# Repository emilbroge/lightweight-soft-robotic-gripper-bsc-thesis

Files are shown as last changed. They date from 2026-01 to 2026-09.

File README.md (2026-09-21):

# Bio-Inspired, Lightweight Soft Robotic Gripper

A lightweight, tendon-driven soft robotic gripper developed as a Bachelor’s thesis at DTU (Neuro Robotics Technology Lab) by Mads August Claussen and Emil Broge Johansen.

The goal of this project was to design a compliant gripper that weighs almost nothing (only 37 g at the wrist!) so it can be mounted onto soft, low-payload continuum robotic arms without weighing them down. Instead of rigid fingers with lots of gears, it uses flexible 3D-printed fingers shaped like an octopus tentacle that wrap gently around objects of different shapes and sizes.

This repository contains the 3D printing/casting files, the Arduino firmware, and the raw experimental data collected for the gripper. It is written so that a future student can pick the project back up: print/cast the parts, wire up the electronics, flash the firmware, and reproduce (or extend) the tests.

https://github.com/user-attachments/assets/c0556c12-12d1-4bf8-a20e-e9f583e94eb2

*(If you are viewing this locally, check out `documentation/gripper-showcase-vid.mp4` and `documentation/gripper_being_operated_and_powered_off.mp4` to see it in action!)*

---

## 1. System Architecture & Mechanism

To keep the hand as light as possible, we separated the "muscles" from the "fingers":

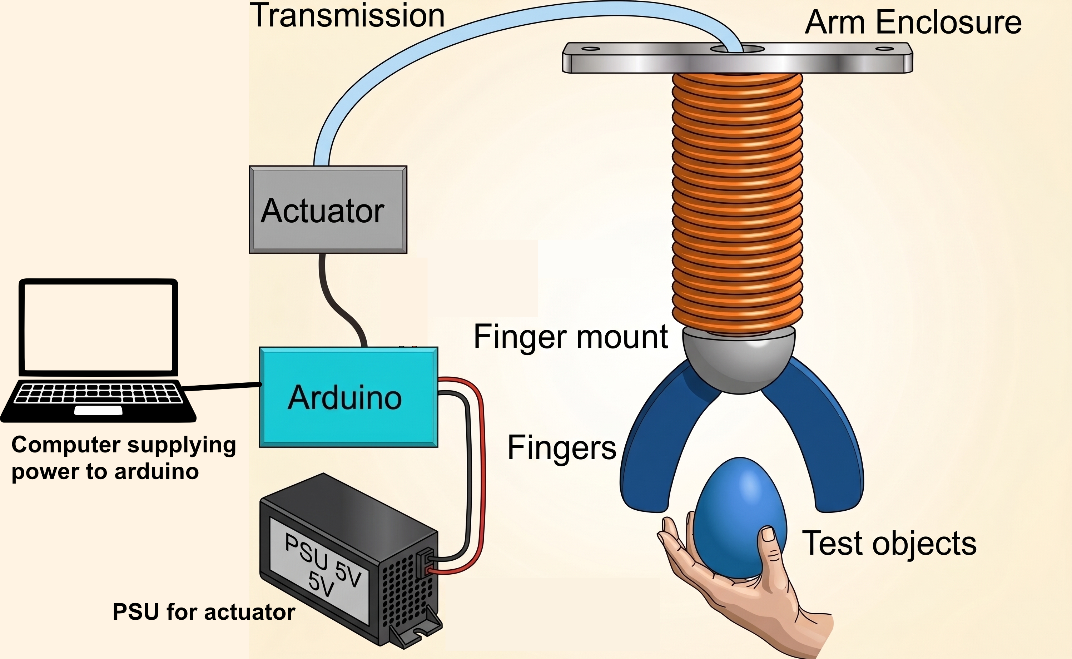
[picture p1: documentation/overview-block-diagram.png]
Gripper System Overview|300


- **External Actuator Box:** Two smart servo motors sit away from the moving arm. One pulls the "flexor" tendon to close the grip, and the other pulls an "extensor" tendon to open it and add stiffness.
- **Bowden Cable Transmission:** The pulling force travels through slick PTFE tubes via strong polyethylene cords (Dyneema).
- **Cable Drum Wrist:** Inside the mount, small spools turn linear cable pulling into rotation without needing a bulky mechanism.
- **Octopus-Inspired Fingers:** The fingers are printed out of flexible TPU with built-in bending joints. They follow a logarithmic spiral shape so they naturally wrap around objects instead of pinching at a stiff angle.
- **Silicone Skin:** A soft silicone layer gives the fingers the grip they need so objects don't slip out.

**Below the gripper can be seen being operated.**

https://github.com/user-attachments/assets/960f5932-b7c9-4243-a79a-f50e997e1e70

---

## 2. Hardware Build Guide

The entire physical build uses affordable 3D-printed parts, standard hobbyist bearings, and two smart servos. The brain of the setup is an Arduino Uno fitted with a motor shield.

All step-by-step guides and CAD drawings are organized in the `documentation/` folder:
- **Parts List & Costs:** See the [Bill of Materials (PDF)](documentation/bill_of_materials.pdf)
- **Step-by-Step Mechanical Assembly:** See the [Assembly Guide (PDF)](documentation/assembly_instructions.pdf)
- **Fabrication & Print Specs:** See the [Hardware & Fabrication Guide](documentation/README.md#1-3d-printing--fabrication)
- **Full Thesis Report:** Read [Full BSc Report (PDF)](documentation/Full_BSc_Report.pdf) for the academic background, math, and design decisions.

---

## 3. Code & Electronics Build Guide

The microcontroller firmware is set up in `code/bsc-gripper/`. It handles motor communication, runs an automatic grip sequence, and streams diagnostic data.

- We use **PlatformIO** (via the VS Code extension) to compile and upload code automatically. [Setting up PlatformIO](code/bsc-gripper/PlatformIO.md)
- **Wiring & Pinout:** See the [Wiring Setup in documentation](documentation/README.md#2-electronics--wiring-setup).
- **Firmware Architecture & Motor Tuning:** See the [Firmware Deep-Dive](code/bsc-gripper/README.md) for pinouts, state machine explanations, and tuning constants in `config.h`.

---
## 4. Experimental Data (`raw_data/`)

All raw test data from our validation trials are available in `raw_data/`:
- `transmission_test/`: Tendon transmission efficiency measurements and `transmission_test.py` to calculate friction coefficients ($\mu$).
- `motor_performance_test/`: Current and force measurements for XL330 and XL430 servos.
- `finger_mount_test/`: Structural and mechanical load data for the finger mount.
- `payload_test/`: Pull-force test data across 11 test shapes (`test_objects.csv` describes dimensions and weights).
- `success_rate/`: Grasp trials (`data_succes.csv`) on real everyday objects.

---

## 5. Potential Improvements

If you're picking up this project for a semester project or thesis, here are several clear areas where you can take it further:

### Hardware Improvements
- **Miniaturization & Cleaner Enclosure:** Redesign the motor box to be smaller and more self-contained. Adding buttons directly to the enclosure would make manual testing much smoother (for example, triggering test routines or toggling live serial output).
- **Easier Finger Assembly:** Threading the tendons and securing the fingers to the mount currently requires a very specific touch and patience. A more modular, snap-in joint design would save a lot of headaches.
- **Self-Contained Power:** The prototype currently relies on a 5V benchtop power supply and a tethered laptop. Integrating a small internal regulator or battery pack would make the setup truly portable.
- **Tendon Terminations:** Finding a cleaner mechanical method to clamp the tendon ends (rather than manual knots) would make string tensioning and length adjustment much more repeatable.
- **User interface:** A simple GUI on a laptop or tablet could allow users to control the gripper, run test routines, and visualize live data without needing to dig into the Arduino code.

### Control Improvements
- **Scientifically Grounded Control:** The current firmware uses a tuned open-loop control. A great next step would be modeling the gripper movements analytically—for instance, using the approach from:
  > Z. Wang and N. M. Freris, *"Exploiting Frictional Effects to Reproduce Octopus-Like Reaching Movements with a Cable-Driven Spiral Robot,"* 2024 IEEE 7th International Conference on Soft Robotics (RoboSoft), San Diego, CA, USA, 2024, pp. 537-542.
- **Grasp Detection:** Use live motor current readings to detect when the fingers touch an object and stop pulling automatically.

---

## Notes for the Next Student

Don't hesitate to reach out, if you have any questions about the project. We are happy to help you get started and point you in the right direction.

- **Mads August Claussen**
- **Emil Broge Johansen**

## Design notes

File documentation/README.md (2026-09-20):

# Hardware & Fabrication Documentation

This guide provides the mechanical and fabrication specifics needed to print, cast, assemble, and wire the gripper.

---

## 1. 3D Printing & Fabrication

All design files are located in the `3d_files/` directory in both editable `.step` and slicer-ready `.stl` formats.

### Recommended Print Settings

| Part | File | Material | Slicer Notes |
|---|---|---|---|
| **Fingers** | `Finger - with supports.stl` | TPU 95A | Print flat on side. Use the version with built-in supports from the file. Speed: 20–30 mm/s. |
| **Finger Mount** | `Finger mount.step` | PLA < PETG < PA-CF | 4+ perimeters, Note: This is very delicate. |
| **Cable Drums** | `Finger mount - * drum half.stl` | PLA < PETG < PA-CF | 100% infill for shaft rigidity. |
| **Arm Interface** | `Finger mount - Arm Interface Cap.stl` | PLA < PETG < PA-CF | Standard print settings (0.2 mm layer height). |
| **Silicone Mold** | `Finger mold.stl` | PLA / PETG | Smooth layer lines help with demolding. |

### Silicone Coating
1. Print the monolithic TPU fingers.
2. Mix a soft 2-part addition-cure silicone rubber.
3. Either pour silicone into `Finger mold.stl` around the finger, or dip-coat the gripping surface. The small retention loops on the finger will lock the cured silicone in place mechanically so it doesn't peel off under shear forces.

---

## 2. Electronics & Wiring Setup

The system uses an **Arduino Uno** with a stacked **Robotis DYNAMIXEL Shield**.
> Future version could use OpenRB-150 instead.

### Pin Connections

| Arduino Pin | Variable in `config.h` | Connection / Device |
|---|---|---|
| **Pin 2** | `DXL_DIR_PIN` | Dynamixel Shield Direction Pin |
| **Pin 4** | `BTN_PIN` | Grip toggle button (connect between Pin 4 and GND) |
| **Pin 5** | `ABC_LOAD_CELL_CLK` | HX711 Clock (optional test rig) |
| **Pin 6** | `C_LOAD_CELL_DT` | HX711 Data (optional test rig) |
| **Pin 7** | `DXL_SHIELD_UART_RX` | SoftwareSerial RX (for computer debug printing) |
| **Pin 8** | `DXL_SHIELD_UART_TX` | SoftwareSerial TX (for computer debug printing) |
| **Pin 9** | `SCOPE_PIN_A` | Timing test pin |
| **Pin 10** | `SCOPE_PIN_B` | Timing test pin |

### Power Supply Warning
> **Warning:** You **must** provide external 5V power to the screw terminals on the DYNAMIXEL Shield. The USB cable alone only powers the Arduino board; the motors will not respond, and the initialization code will hang in a ping loop until external power is supplied. This should be fixed in a future version.

---

## 3. Assembly References

For detailed mechanical assembly steps, see the PDFs included in this folder:
- **`assembly_instructions_compressed.pdf`**: Exploded-view diagrams showing how to press-fit the bearings, assemble the drums, route the cords, and attach the unit to the robot arm. > [!NOTE]
> The flexor and extensor tendon pairs must be equal in length to prevent asymmetrical finger movement during flexion and extension.
- **`bill_of_materials_compressed.pdf`**: Itemized list of fasteners, bearings, wire, tubing, and electronics with part numbers and supplier links.

The getting the wires through the fingers can be tricky. Contact us for tips if you are having trouble.

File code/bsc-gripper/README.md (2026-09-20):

# Gripper Firmware Guide (`code/bsc-gripper`)

This folder contains the PlatformIO firmware project targeting an Arduino Uno (`env:uno` in `platformio.ini`) equipped with a Robotis DYNAMIXEL Shield.

> **Legacy Firmware Note:** The earlier non-PlatformIO firmware (`code/main_firmware_version/`) has been deprecated and superseded by this project.

---

## 1. Project Structure & Responsibilities

| File | Purpose / Responsibility |
|---|---|
| `src/main.cpp` | Main loop, button debounce, state machine, periodic sampling, and serial formatting. |
| `src/config.h` | All hardware pins, tuning parameters, motor IDs, safety limits (PWM/Current), load cell scale factor, and timing periods. |
| `src/dynamixel_control.{h,cpp}` | DYNAMIXEL communication via `Dynamixel2Arduino`, sync-write packet packing, feedback reading, and the grip state machine (`dxl_update_state()`). |
| `src/load_cell.{h,cpp}` | Reading and calibrating the optional HX711 load cell sensor (active when `debugLoadCells = true`). |
| `src/serial_config.{h,cpp}` | Configures `SoftwareSerial` pins for telemetry output. |

---

## 2. Crucial Hardware Quirks

### 1. The Single Hardware UART on Arduino Uno
The Arduino Uno has only one hardware serial port (`Serial`, pins 0 and 1). This hardware port is entirely dedicated to the high-speed half-duplex DYNAMIXEL bus running at **1,000,000 bps** (`dxl.begin(1000000)`).
- **Debug output cannot be sent over standard USB Serial.**
- Telemetry is transmitted via `SoftwareSerial` on **Pins 7 (RX)** and **8 (TX)** at **115200 baud**.
- To read debug logs on your PC, connect an external USB-to-UART adapter (FTDI / CP2102) to pins 7 and 8.

### 2. Motor Power & Voltage Verification
> **Critical:** Always check your servo model's operating voltage before applying bench power!
> - **XL330 series:** Rated for **5.0V** (operating range 3.7V – 6.0V). Connecting a 12V supply will destroy them.
> - **XL430 series:** Rated for **11.1V – 12.0V**.

During startup, `dxl_init()` executes a blocking `while` loop:
```cpp
while (!dxl.ping(DXL_ID_FLEXOR) || !dxl.ping(DXL_ID_EXTENSOR)) {
    delay(1000);
}
```
If the motors do not have external power connected to the shield screw terminals, or if the motor IDs do not match `DXL_ID_FLEXOR` (`9`) and `DXL_ID_EXTENSOR` (`8`), the board will hang here indefinitely.

---

## 3. One-Time Servo Setup (DYNAMIXEL Wizard 2.0)

Before wiring both servos onto the shared bus, plug each servo into a computer individually (using a U2D2 or USB adapter) and configure them via **DYNAMIXEL Wizard 2.0**:

1. Set **Baud Rate** to `1,000,000 bps`.
2. Set **Protocol** to `2.0`.
3. Set IDs:
   - Extensor Servo: **ID 8**
   - Flexor Servo: **ID 9**
4. Check that operating mode is accessible (the firmware automatically sets `OP_PWM` during setup).

---

## 4. Grip State Machine & Control Strategy

The gripper uses an antagonistic PWM profile across five states defined in `dynamixel_control.cpp`:

```text
[GRIP_OPEN]
     │ (Button press / grip = true)
     ▼
[GRIP_CLOSING]    --> Flexor ramps up with CLOSING_FLEX_SLOPE, extensor applies slight drag
     │ (Flexor reaches CLOSING_FLEX_LIMIT)
     ▼
[GRIP_TIGHTEN]    --> Peak PWM applied to overcome friction and seat the tendons
     │ (Flexor reaches TIGHTEN_FLEX_LIMIT)
     ▼
[GRIP_HOLDING]    --> PWM drops to low holding level (HOLDING_FLEX_LIMIT) to prevent motor heating
     │ (Button press / grip = false)
     ▼
[GRIP_RELEASING] --> Extensor pulls high (RELEASING_EXTE_LIMIT) while flexor releases
     │ (Extensor velocity slows & position reached)
     ▼
[GRIP_OPEN]
```

### Key Tunables in `config.h`
- `MAX_PWM` (default `600`): Maximum allowable PWM duty written to the registers.
- `MAX_CURRENT` (default `300`): Maximum allowable current limit.
- `CLOSING_FLEX_SLOPE` & `CLOSING_FLEX_LIMIT`: Adjust how quickly and firmly the hand initially curls.
- `HOLDING_FLEX_LIMIT` (default `250`): Steady-state holding power. Keep this low to avoid overheating the XL330 motors during continuous grasps.
- `SAMPLING_PERIOD_MS` (default `100`): Frequency of state updates. *Note: If using the HX711 load cell, this must remain >= 100 ms due to the 10 SPS ADC conversion rate*.
- `C_LOAD_CELL_SCALE`: Calibration factor for the HX711 amplifier. If you mount a new strain gauge beam, calibrate this value using known test weights.

---

## 5. Notes on Auto-Calibration & Homing

- In `main.cpp`, you will notice a commented-out call: `// dxl_auto_calibration(250);`. This was an experimental auto-homing feature that was never fully implemented.
- The current firmware operates in open-loop PWM mode. Therefore, **the motors must start at their neutral open position when powered on**. Ensure tendon slack is taken up before running the state machine.

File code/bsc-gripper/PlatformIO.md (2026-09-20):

# PlatformIO Setup & Build Guide (`code/bsc-gripper`)

This guide covers setting up your development environment, building, flashing, and monitoring the gripper firmware using **PlatformIO**.

> **Note on Legacy Code:** The older codebase in `code/main_firmware_version/` has been completely superseded by this PlatformIO project. All future development, bug fixes, and testing should occur inside `code/bsc-gripper/`.

---

## 1. Prerequisites & Installation

You can develop using either the VS Code graphical environment or the command-line interface.

### Recommended way

1. Install [VS Code](https://code.visualstudio.com/) and the **PlatformIO IDE** extension
   (already recommended in `.vscode/extensions.json` — VS Code should prompt you to install it
   when you open `code/bsc-gripper`).
2. Open the folder `code/bsc-gripper` in VS Code (not the repo root — PlatformIO looks for
   `platformio.ini` in the opened folder).
3. Let PlatformIO install the `atmelavr` platform and the two libraries from `platformio.ini`
   on first build (it does this automatically).

### Other options
   - Alternatively, install the [PlatformIO Core CLI](https://docs.platformio.org/en/latest/core/installation/index.html).
   - Install PlatformIO Core via Python `pip`:
```bash
pip install -U platformio
```

> **Important:** Always open the subfolder `code/bsc-gripper` as the root workspace in VS Code, **not** the entire repository root. PlatformIO requires `platformio.ini` to be located directly at the workspace root to parse the project configuration.

---

## 2. Building, Uploading & Monitoring

Connect your Arduino Uno via USB. Stack the Robotis DYNAMIXEL Shield on top and connect external power to the shield's screw terminals.

### GUI (VS Code PlatformIO Toolbar)
Use the icons located in the bottom status bar:
- **Build:** Click the checkmark icon (`PlatformIO: Build`).
- **Upload:** Click the right arrow icon (`PlatformIO: Upload`).
- **Serial Monitor:** Click the plug icon (`PlatformIO: Serial Monitor`).

### Command-Line Interface (CLI)
From inside the `code/bsc-gripper/` directory:

```bash
# Compile the firmware
pio run

# Compile and upload to the connected Arduino Uno
pio run -t upload

# Open the serial monitor (115200 baud)
pio device monitor -b 115200
```

---

## 3. Hardware Quirks & Telemetry Setup

### Debug Telemetry Over SoftwareSerial
The Arduino Uno has only one hardware UART (`Serial`, pins 0 and 1), which is dedicated to the half-duplex DYNAMIXEL bus running at **1,000,000 bps**.

- **Debug logs will not appear over the default Arduino USB connection.**
- Debug telemetry is transmitted via `SoftwareSerial` on:
  - **Pin 7:** RX
  - **Pin 8:** TX
- Connect an external USB-to-UART adapter (such as an FTDI or CP2102 adapter) between pins 7/8 and your computer:
  - Adapter RX $\rightarrow$ Arduino Pin 8 (TX)
  - Adapter TX $\rightarrow$ Arduino Pin 7 (RX)
  - Adapter GND $\rightarrow$ Arduino GND
- Monitor the adapter's COM/TTY port at **115200 baud** to see the tab-separated telemetry (servo PWM, current, position, velocity, load cell forces, and state counter).

### Motor Power Requirement at Boot
During `setup()`, the firmware runs a blocking loop:
```cpp
while (!dxl.ping(DXL_ID_FLEXOR) || !dxl.ping(DXL_ID_EXTENSOR)) {
    delay(1000);
}
```
The Arduino will hang here indefinitely if:
1. External power is not applied to the DYNAMIXEL Shield's screw terminals (USB alone cannot power the servos).
2. The servo IDs in DYNAMIXEL Wizard do not match **ID 8** (extensor) and **ID 9** (flexor).
3. The baud rate of the servos is not set to `1,000,000 bps`.

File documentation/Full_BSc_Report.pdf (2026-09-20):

# Technical University of Denmark

# Design and development of a

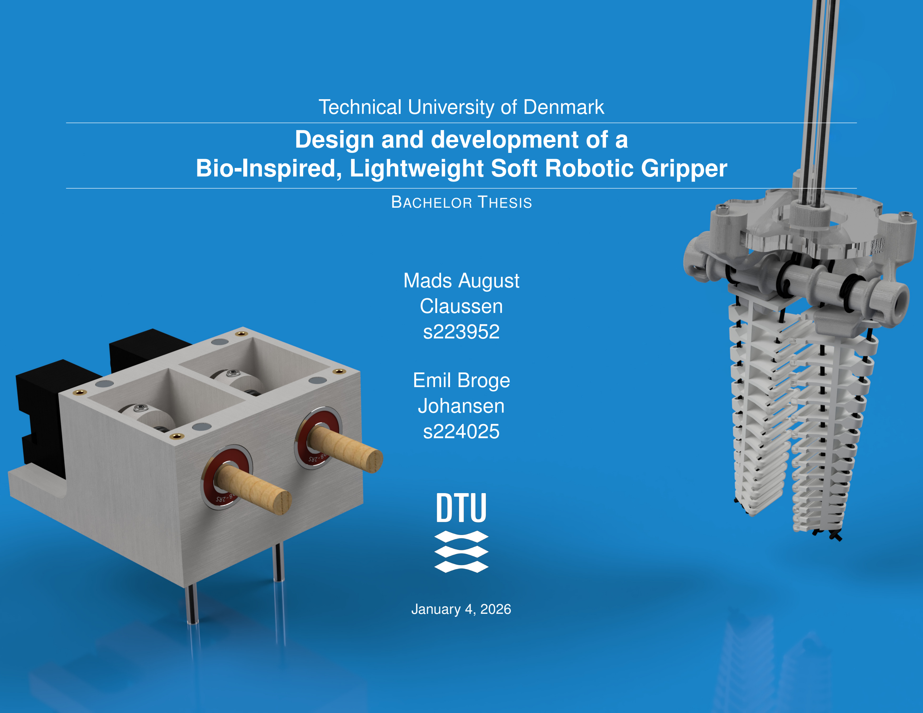
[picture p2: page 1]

# Bio-Inspired, Lightweight Soft Robotic Gripper

BACHELOR THESIS

# Mads August Claussen

s223952

# Emil Broge Johansen

s224025

### January 4, 2026

## Abstract

Soft robotics offers inherent compliance and adaptability, enabling safe interaction with fragile and irregularly shaped objects. However, this compliance often comes at the cost of structural integrity and low payload capacity, a limitation that is also present in soft continuum robot arms. Because of the low payload capacity of such soft robot arms, mounted end-effector are constrained by weight and space limits. Therefore there is a need for the development of a lightweight soft robotic gripper.

This report presents the design and prototyping of a lightweight, servo-motordriven, tendon-actuated soft robotic gripper. The gripper consists of two silicone coated monolithic 3D-printed TPU fingers. The fingers are mounted on a 3D-printed PLA finger base incorporating miniature tendon drums and bearings, enabling compact tendon force distribution without the bulk of normally used tendon distribution mechanisms. Actuation and control are handled by an externally mounted module consisting of a microcontroller and servo motors, employing a bio-inspired control strategy based on octopuslike wrapping motion.

The gripper is experimentally evaluated using payload and grip success tests on a defined set of test objects. The final gripper weighs 37 grams and achieves a maximum lifting capacity of approximately 100 grams in pinch grasping and up to 750 grams in wrapping grasping. In figure 1 the main components of the system are presented graphically.

The code used, the STL files for 3D print and the raw test data can be found in the public GitHub repository: https://github.com/emilbroge/lightweight-soft-robotic-gripper-bsc-thesis. (https://github.com/emilbroge/lightweight-soft-robotic-gripper-bsc-thesis) Code has also been uploaded with the report as External Appendix I.

Figure 1: a) Actuator module, mounted external to the arm b) Gripper mounted on the NRT Lab arm - actuator and gripper are connected via two tendons running in PTFE tubes

Page 1 of 70

## Acknowledgements

We would like to thank our supervisors Silvia Tolu, Torben Lenau and Søren Hansen for guiding us through this project.

We would like to thank our friend Jakob Guarini for letting us use his 3D printer extensively for prototyping.

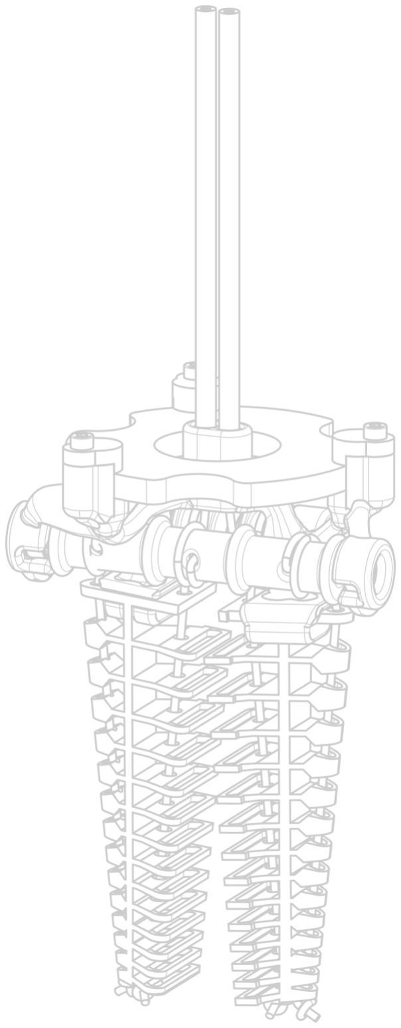
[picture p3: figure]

Page 2 of 70

## Part I

# Project

Table of Contents

1 Introduction | 4
2 Project overview & Design Requirements | 4
3 Previous Grippers | 9
4 Conceptual Design | 13
5 Embodied design | 31
6 Final design | 46
7 Testing and results | 47
8 Discussion | 52
References | 54
Distribution of work | 56
Appendix | 57

Page 3 of 70

2 PROJECT OVERVIEW & DESIGN REQUIREMENTS

## 1 Introduction

Because of its inherent compliance and ability to handle complex objects, soft robotics is an emerging field within robotics. Soft robotics focuses on the use of deformable and flexible materials in place of conventional rigid metals and plastics. Beyond material choices, soft robotics often uses alternative actuation methods such as flexible fluid actuators (FFA) or tendon-driven mechanisms, rather than traditional rigid gears and links mechanisms. In the case of grippers, soft robotic designs enable solutions that inherently adapt to objects of varying shapes, sizes, and friabilities while maintaining safety in human environments. However, the inherent compliance of soft robots also limits their strength and load-bearing capacity, mainly due to a lack of mechanical rigidity. Therefore, it is desirable to develop a lightweight, soft robotic end-effector that can be mounted onto low-strength, soft robotic arms.

### 1.1 Problem statement

To enable the gripping of diverse objects, the gripping mechanism needs to conform properly to the gripped objects. In traditional rigid robotics, this is often achieved using many sensors, actuators and complex control techniques. The use of biologically inspired design realized through compliant materials and mechanisms is advantageous for performing this gripping task. The use of a compliant mechanical design should also reduce the amount of complex control algorithms needed. However, exactly because of this compliance (lack of rigidity), the mechanism is likely to be less predictable which can pose a potential challenge for precise movements. The project aims to investigate:

- How has a similar gripping task been solved previously in literature?
- Which mechanical mechanisms and materials are suitable for this task?
- What electrical framework is needed to realize such a system?
- How can the performance of this gripper be evaluated?

## 2 Project overview & Design Requirements

### 2.1 Project scope and goals

This project aims to develop a novel end-effector for the Neuro Robotics Technology Lab (NRT-Lab) continuum robot arm. Currently, the robot arm uses velcro tape as the interface between arm and payloads. The robot arm has previously been tuned and controlled with payloads up to maximum 100 grams. This means that the developed gripper should weigh as little as possible, if any payload at all is to be lifted.

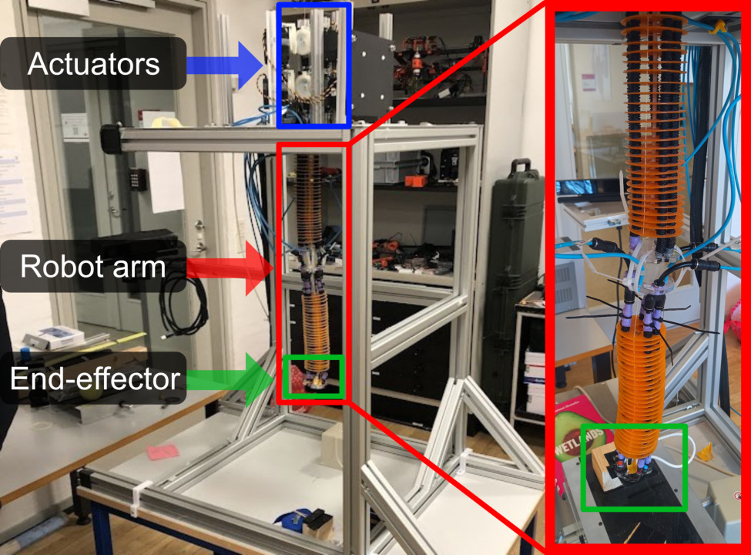
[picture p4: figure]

Figure 2: The soft continuum robot arm in the Neuro Robotics Technology Lab (NRT-Lab). This is the robot arm that we need to develop an end-effector for.

The NRT arm is attached to a metal "enclosure", where the motors moving the arm itself are displaced. This means that we in the design of the end-effector can utilize this space - if needed. Eg. a displacement of the actuators, to save weight on the end-effector itself.

The project aims to accomplish the following high-level goals:

Page 4 of 70

2 PROJECT OVERVIEW & DESIGN REQUIREMENTS | 2.2 Project methods
- End up with a lightweight first prototype of the end-effector
- Grip and hold certain test objects (to be defined)
- Actuate the gripper automatically and fast
- Test the gripper’s functionality when mounted on the NRT robot arm

### 2.2 Project methods

The project employs a systematic approach to developing the gripper, beginning with research into existing robotic grippers and biological systems for inspiration. After establishing an informed initial design direction, the development follows an iterative process, which also dictates the structure of this report:

1. Conceptual design: Draw on academic literature, bio mimicry, and structured brainstorming to generate concepts.
2. Embodied design: Realize selected concepts as prototype(s) using CAD, 3D printing, silicone casting, and related fabrication techniques.
3. Testing & results: Perform experimental testing to quantify performance (e.g., grasp success, payload) and compare results against project targets.

While the electrical, control and mechanical design processes are intertwined, the above mentioned process is especially important to the mechanical design process.

What is problem-driven, bio-inspired design?

Problem-driven, bio inspired design (BID) is a methodology to make innovative engineering solutions, by looking to nature for inspiration. This approach has been shown to significantly increase the generation of highly novel concepts compared to traditional design methods [1]. There are five phases in the framework: [2]

1. Problem Analysis: The technical problem is defined and the demands and criteria are abstracted by re-framing requirements (e.g., focusing on "attachment" rather than "glue").
2. Search: Potential biological strategies are identified through databases or literature, looking for organisms that have evolved to solve the abstracted functions.
3. Understand: The biological strategies are analyzed to understand the underlying principles.
4. Transfer: This is the bridge where the biological strategy is translated into technical principles, stripping away the biological context to focus on what is technically feasible.
5. Design: The transferred principles are implemented into a manufacturable engineering design and validated against the original technical needs.

We went through the first three steps in our preliminary work (External Appendix II), but when further developing the different subsystems of the gripper we will use this methodology as a framework to find the means to perform the desired functions.

Another reason to use bio inspired design, is making communication easier, since it is more tangible to relate to something that resembles nature. This also makes naming easier and more systematic.

### 2.3 Prior work

This thesis builds directly upon the preliminary research that we conducted in the special course report "Soft Robotics Gripper Review" (see External Appendix II). The report investigates a wide variety of grippers found in literature and nature. This includes analyzing the different technologies and methods used in different types of grippers.

The prior work established a framework for analyzing soft grippers by defining five subsystems, enabling us to gain an overview of the design space. The five subsystems that we identified were:

1. Dry adhesion: This includes different technologies to better adhere to a surface, while being able to remove the adhesion quickly again. The

Page 5 of 70

2 PROJECT OVERVIEW & DESIGN REQUIREMENTS | 2.4 Requirements

main dry adhesion methods found were silicone, electro adhesion and
gecko-skin.
2. Gripper Morphology: This is the geometry, mechanical layout and kinematics of the gripper. Grippers in nature were described using its degrees of freedom, contact conditions and geometry.
3. Actuation: This is the means to which a control signal is converted to movement. We looked into DC motors, pneumatics, shape memory alloys and dielectric elastomers.
4. Control: The strategies used to control the gripper. This mainly involves the properties of the control signal to the actuators.
5. Energy Supply: The power infrastructure needed to control the gripper. Could be simple low voltage batteries, high voltage converts or pressure reservoirs.

These different categories are of course intertwined, but listing them like this, made it easier to navigate in the vast amount of soft grippers.

Evaluated Design Concepts

The previous study transformed these technologies into two distinct design concepts, serving as the departure point for this project:

- Compliant Tendon Design: This concept mimics the human hand by using DC motors to pull artificial tendons through compliant, underactuated fingers. It was found to offer high controllability and sensor feedback (via motor current/encoders) but introduced mechanical complexity regarding friction and tendon routing.
- Pneumatic Design: This concept utilizes a silicone elastomer structure, fabricated via 3D-printed molds, which is actuated by a remote external pressure reservoir and controller (to minimize end-effector mass). Compliance and movement are managed through internal geometry or particle jamming. This offers a scale of complexity from a single-DOF system to multi-compartment fingers for independent control. Because pneumatic systems lack inherent feedback, integrated sensors (e.g. piezo-resistive sensors) are required to monitor bending angles.

While dry adhesion, such as gecko skin or electro adhesion, can be integrated to enhance the contact conditions for both concepts, these additions introduce fabrication complexity. For gecko skin we have directional release constraints, and for electro adhesion high-voltage safety concerns. Therefore, we chose not to go forward with a focus on dry adhesion.

The conclusion of the previous report demonstrated that no single subsystem offers a universal solution; rather, the design must balance fabrication complexity with grip strength and weight.

### Choosing design concept from the prior work

To focus the scope of this project, a specific design concept was selected from the preliminary research. To do this while mitigating subjective bias, we used a weighted decision matrix to quantify the performance of each design concept (appendix H). To test the reliability of our results, we introduced two alternative weighting sets: one emphasizing cost and the other focusing on strength and efficiency. These variations acted as a sensitivity check for our decision. The results in Table 1 show that the tendon-driven concept consistently outperformed the alternatives, leading us to proceed with this design.

Score type | Tendons | Pneumatics
Primary weighted score | 4.21 | 4.01
Weighted score with strength sensitivity | 4.35 | 3.92
Weighted score with cost sensitivity | 4.24 | 4.09

Table 1: The primary and weighted scores from appendix H for tendon and pneumatic systems. We made one score heavily emphasizing strength, and one including cost. The scale goes from 1 to 5.

### 2.4 Requirements

To make the design and evaluation process easier, we defined some specific requirements, stemming from the problem definition. This serves as a guideline when taking design decisions. We will go through these now. They are also formulated in table 2.

Page 6 of 70

2 PROJECT OVERVIEW & DESIGN REQUIREMENTS | 2.4 Requirements
Requirement | Measure | Justification
Gripper weight | max. 40 g | Not to overcome the max payload of the robot arm
Load bearing | up to 60 g | To utilize the whole weight from 40 g (gripper weight) up to 100 g (max. pay-load)
Reliably grasp and hold test objects | 90% success rate | -
Handle both rigid and soft objects | True/False | To grasp all the test objects
Grasp width | 0.5-3 cm | To grasp all the test objects. Max width of test objects is 3 cm
Withstands repeated grasping of test objects without failure | - To operate for longer, the gripper needs to be durable
Speed | < 3 s | For human interaction, measured from open state to closed state
Mountable on the end of the NRT Lab robot arm | True/False | This is the main task of the project
Transmission able to fit inside the NRT Lab robot arm | Diameter < 10mm | Transmission should be mounted internally, for a less intervening mounting.
Low Control Complexity | - | In interest of time and scope of the project. Only feed forward control, unless closed-loop is already implemented in motors.
Low Assembly Complexity | - | Since we have limited tools and equipment available, and for easy repro-ducibility. E.g. 3D printable.

Table 2: Overview of requirements of the gripper

As mentioned in the intro, the NRT-Lab robot arm can only support up to 100 grams including end-effector and payload. Because of this, we set a restriction of the weight of the gripper to 40 grams. This results in a required gripper load bearing of up to 60 grams. It is advantageous if the load bearing exceeds the 60 grams, since the gripper then potentially can be used on other robot arms.

As will be mentioned in the next subsection, we define some test objects to evaluate the gripper against. These test objects vary in size, shape and hardness. Thus the gripper needs to be able to handle these very different

objects reliably.

As the NRT Lab robot arm is (also) designed for human interaction, the operation speed needs to be relatively fast. We assessed that a closing time below three seconds is sufficient as a novel target. Additionally, as the gripper needs to be mounted on the robot arm, this is obviously also a requirements
- this includes being able to mount the transmission inside the arm and the gripper on the end of the arm.

As we have limited time and resources, the design and implementation complexity should be relatively low, this includes the control complexity and as-

Page 7 of 70

2 PROJECT OVERVIEW & DESIGN REQUIREMENTS | 2.4 Requirements

sembly complexity.

Test Objects

We want to have a set of objects to test the gripper against. These objects should have varying parameters, such as mass, center of gravity, surface and shape, thus illustrating different challenges of gripping. Furthermore, they should be normal everyday items, as these pose a more realistic gripping challenge. As mentioned earlier, the maximum payload of the NRT-Lab arm is around a 100 grams. This means that the mass of the test objects should be at or below ca. 50-60 grams, since the max gripper weight is set to maximum 40 grams. In the following list we see a definition of the test objects. A graphical overview can also be seen in fig. 4.

- Lego brick: (3 g) This is a small item, requiring dexterity.
- Sponge: (5 g) A lightweight "squishy" object.
- Tape: (17 g) Allows wrapping through its center hole, but also poses a challenge if wrapped around, because of the low friction of the tape surface.
- Cutlery: (26 g) This is a difficult task since the cutlery is very thin, and the gripper has to resist a rotational moment.
- Cloth: (39 g) This object is very deformable.
- Pill container: (50 g) Object with flat surface and relatively heavy
- Egg: (55 g) Eggs are fragile (with unevenly distributed force) and therefore difficult to grasp without destroying if using a traditional gripper. Also, the mass of an egg (55 grams) is close to the maximum carrying capacity.

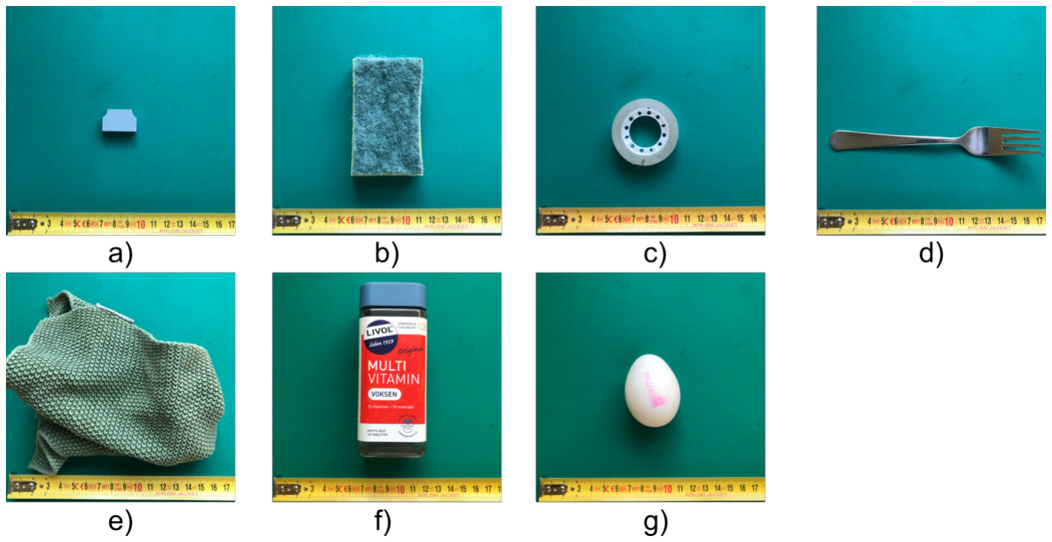
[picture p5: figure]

Figure 4: Test objects: a) "Lego" brick (3 g) b) Sponge (5 g) c) Tape (17 g)
d) Cutlery (26 g) e) Cloth (39 g) f) Pill container (50 g) g) Egg (55 g)

Apart from these very realistic everyday test objects, we will in the testing of the gripper introduce a set of more standardized test objects. Here standardized refers to the fact that the object are simple shapes (box/sphere), with varying dimensions that we 3D print out of the same material every time. These objects will serve as a more quantitative test object.

This concludes the project overview and design requirements section. This is the basis for our further research of the problem and design space.

Page 8 of 70

3 PREVIOUS GRIPPERS

## 3 Previous Grippers

As a starting point for the design and development of the gripper, we take a look at how similar tasks have been solved previously. The prior work focused on general soft robotic grippers. Here we will limit ourselves to tendon driven robotic grippers. The amount of soft robotic grippers is large, but in the following we have selected some, that we feel are interesting specifically for our problem. In our research we found that the following topics are among the most relevant in (DC motor, tendon driven) soft robotic grippers:

- Bio mimicry: How are soft robotic grippers inspired by biology?
- Balancing softness and rigidity: Compliance and strength
- Under actuation: To what degree is underactuation used.
- Amount of control: How are the tendons actuated, sensing, modeling
- Weight/size of gripper, is actuator internal or external.

Figure 5: Screenshot of the graphical abstract of SpiRobs [3].

Wang et al. [3] created SpiRobs, a bio-inspired end-effector. It is based on the logarithmic spiral an octopus or elephant makes when curling their tentacle/trunk, and is able to grab, release and move, using only two tendons. A clever antagonistic multi-stage actuation strategy enables various different movement patterns, like reaching, curling up, grasping etc. The octopus design was both realized as a single-tentacle, combined arm + end-effector design, and as a multi-tentacle pure end-effector. The tentacles were realized as 3D printed thermoplastic polyurethane (TPU) with living hinges as the joints. The graphical abstract for SpiRobs can be seen in figure 5.

The team behind SpiRobs also made a follow-up article showing how they exploit friction to make different movement patterns. They made a mathematical model of the gripper in which they modeled the friction in the tendons inside the robot, using the Capstan equation ( Fin

Fout

= e

µθ). By pulling with different amounts of force in the cables, they apply different amounts of tension inside the robot, and thereby "stiffness". Depending on the tension distribution inside the robot, different movement patterns can be created by pulling the different cables [4].

Crooks et al. [5] made a very simple two finger gripper using compliant mechanisms. It is inspired by the structure of fish fins (Fin Ray®). The gripper is made of TPU and actuated by a DC motor. The actuation happens through the compliant mechanism and is hence underactuated. The amount of control is very simple in this design, since it relies on the springiness of the TPU, to return to an open grip state. One of the prototype from Crooks et al. can be seen in the top left corner of figure 6.

Another two-finger gripper was made by Godaba et al. Their gripper includes a variable stiffness mechanism achieved by actuation of pneumatic "stiffness pouches" resulting in actively controlled grasp modes. Though the stiffness mechanism itself is actuated by pneumatics, the finger actuation is done directly with a servo motor [6]. This gripper is seen at the bottom of figure 6.

Page 9 of 70

3 PREVIOUS GRIPPERS

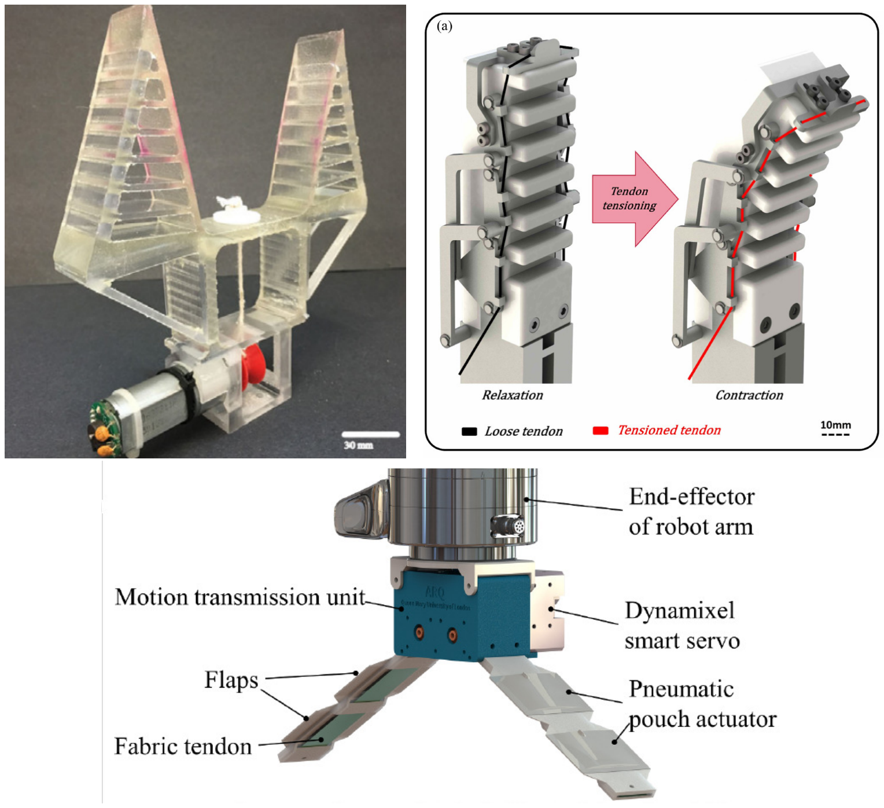
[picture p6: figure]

Figure 6: Top-Left: Screenshot of the FinRay®effect gripper by Crooks et al. [5], Top-Right: Antagonistically induced variable stiffness mechanism of a servo driven silicone finger from Suo et al. [7] (screenshot), Bottom: Two-finger servo actuated gripper with variable stiffness pneumatic pouches [6] (screenshot)

In our design task, the weight and size of both the mechanical and electrical parts play a vital role. Moving from a two-finger design to a three or even five-finger design will potentially increase the implementation complexity and form-factor. However, we will still take inspiration from these multi-finger designs, since the principles applied are still useful.

The first example of multi-finger mechanisms using underactuation comes from Ma et al. [8]. Together with the Yale OpenHand project they made an affordable 3d printable gripper, using only one motor. It is based on a simple differential pulley force distribution system. As they put it: "Underactuated hands have been shown to improve the generality of simple grippers by adaptively conforming to the surface of objects without the explicit need for sensors or complicated feedback systems." [8]. The hand has four fingers with two joints each creating eight degrees of freedom. These eight joints are all pulled at the same time and the pulley mechanism passively distributes the load among the fingers, creating a grasp that conforms to the objects being gripped. This gripper can be seen to the left in figure 7.

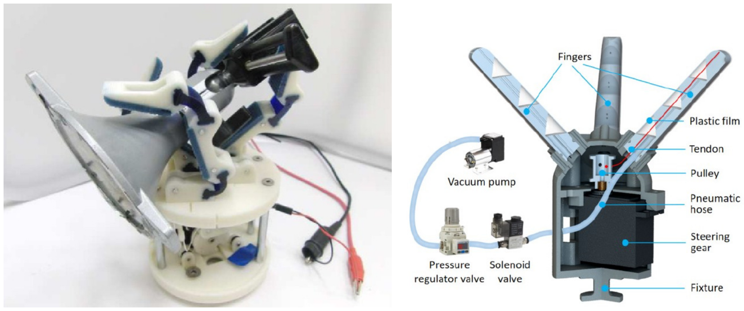
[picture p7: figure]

Figure 7: Left: Yale OpenHand Model T grasping a irregularly shaped object [8] (screenshot) - the fingers conform to object due to the under actuation pulley load distribution system, Right: Combined pneumatic and tendon driven three-finger gripper. Fingers are 3D printed from TPU, and tendons are driven directly by a servo motor. [9] (screenshot)

Zhu et al. [9] made a combined pneumatic and tendon driven tri-finger gripper using TPU as the structure of the finger and a servo motor as the tendon driver. This gripper illustrates the difference in grasping performance and characteristics, between pneumatic and servo actuation. Furthermore, it shows a fully 3D printed TPU finger design. See the prototype to the right in figure 7.

Sou et al. [7] made a variable stiffness (antagonistic tendons exoskeleton) tri finger underactuated gripper with silicone fingers. This design showed an improvement in finger rigidity, when using the antagonistic exoskeleton. However, the tendon drive exoskeleton increases integration complexity and

Page 10 of 70

3 PREVIOUS GRIPPERS

part count. The design can be seen in the top right corner of figure 6.

Moving onto grippers with more fingers, that mimic the human morphology -so called anthropomorphic grippers. We start with the most elemental form -an almost exact replica of a single human finger.

The human finger structure has been replicated by Liu et al. [10] and can be seen in fig. 8. This finger is a very direct form of bio-inspiration, to the point where it could almost be called bio-replication. The finger is actuated using a shape memory alloy wire, and ligaments are replicated using fabric.

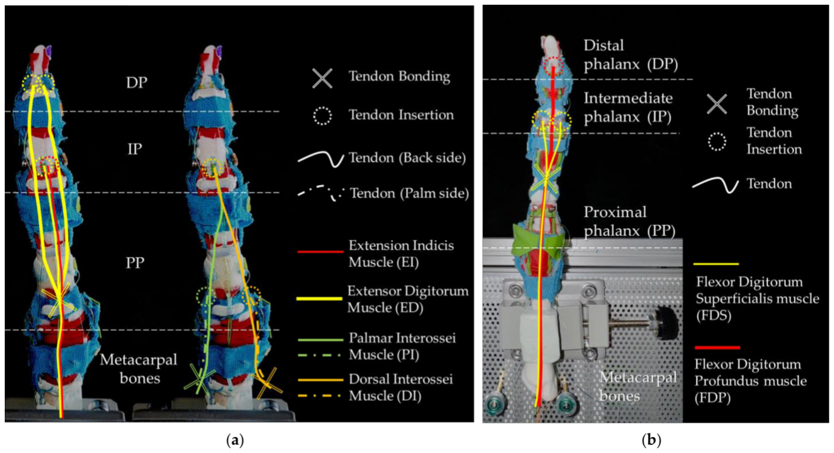
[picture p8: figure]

Figure 8: Liu et al. [10] (screenshot): Illustration of insertion of the muscle tendons: (a) tendon of extension muscles (view from back side); (b) tendon of flexion muscles (view from palm side). This is an example of bio replication.

Li et al. [11] have created a highly underactuated antagonistically tendon driven gripper. This gripper mimics the human hand, and includes a specific tendon guiding system. They proposed different control sequences (see figure 9) to the flexor/extensor motors, that each result in a different hand gesture. This is a way of achieving a sort of control of the actuation, while still getting the benefits of the under actuation. For guiding the tendons, they use miniature pulleys hence eliminating a lot of friction - while increasing the mechanical build complexity. This differs from the SpiRobs strategy, which instead exploits the friction for controlling the fingers/tentacles. The tendons are connected to a common axle, one for the flexor and one for the extensor. This axle is directly rotated by servo motors. Between the servo axle and the hand itself, springs are place to ensure a coordinated movement of each finger - this however increases the length of the base of the gripper. This gripper can be seen in figure 9.

Figure 9: Motor control inputs of Tactile SoftHand-A from Li et al. [11] (screenshot). It can be seen that different actuation curves results in different grasp modes.

Page 11 of 70

3 PREVIOUS GRIPPERS

Bombara et al. [12] made a soft silicone gripper, also using antagonistically actuated flexor/extensor tendons. The special thing about the proposed gripper is the twisted tendon actuation. This actuation type allows for very little space to be used for DC motor, since the gearing is inherent to the twisted string, instead of being present as gears in a servo motor. However, the twisting part of the tendons usually also need a section to rotate freely in, thus using extra space. By using a single silicone mold for the entire hand, they ensure a soft and high friction contact area no matter the grasp modes. The question of structural integrity (stiffness) is solved by using PTFE tubes (for tendon guidance) and as the "bones" of the hand - resulting in a constant stiffness.

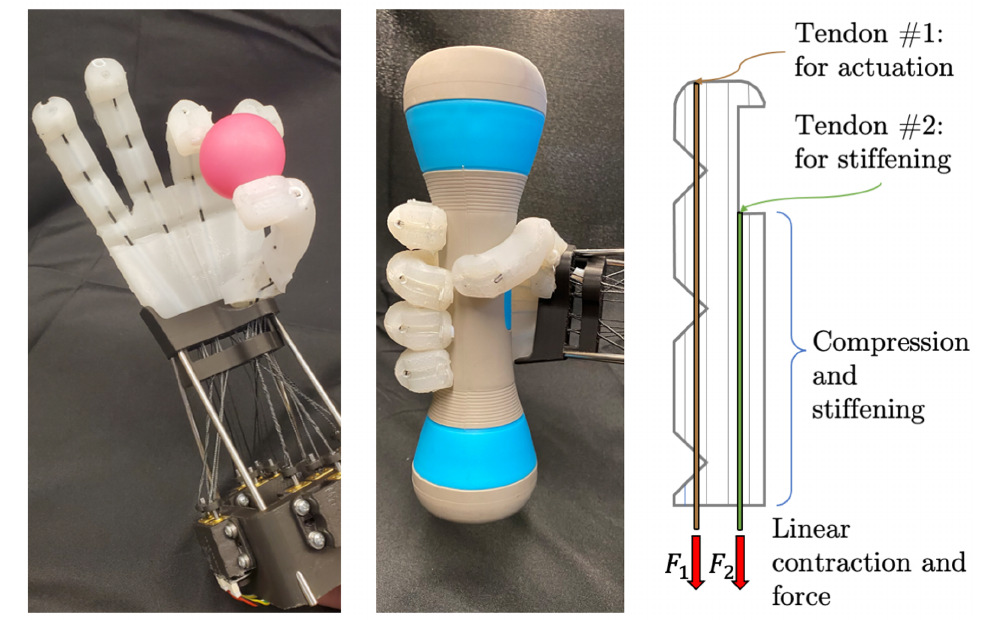
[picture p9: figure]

Figure 10: Tendon setup for the soft robot hand made of silicone proposed by Bombara et al. [12] (screenshot)

Common for all of these grippers is the internal placement of the actuators. Meaning that the motors are placed inside the gripper itself. This increases the weight of the gripper substantially, and should ideally be tackled differently in this project, since the weight is important.

Additionally, most of the mentioned grippers contain a tendon distribution system, that takes up quite a lot of space (and thus also weight). By tendon distribution system, we refer to the space between the actuators and the fingers, that often constitutes itself as a "bulky" box at the base of the grippers. Again, due to weight constraints, this also seems like a challenge that we have to deal with differently in this project.

The reviewed grippers demonstrate varying degrees of bio mimicry, ranging from direct morphological imitation to the transfer of abstract biological concepts. For the reviewed grippers, the latter approach results in reduced mechanical complexity, which is a critical factor for the weight and size constraints of this project.

Figure 11: Diagram showing the balance and tradeoff between rigid/soft robots.

Another challenge identified is the balance between a soft and a rigid structure. This is the tradeoff that is inherent to the original motivation for using soft robots - the ability to conform to objects automatically. This ability directly results in a decrease of structural strength and performance. As we have seen from the previous grippers, one way of solving this challenge is by the use of variable stiffness, like pneumatic pouches or, more relevant to this project; antagonistic tendon movement.

With the principles and concepts of these previously developed grippers, we will now begin the development of our gripper. We start at the conceptual design phase in the following section.

Page 12 of 70

4 CONCEPTUAL DESIGN

## 4 Conceptual Design

In this chapter, we translate the problem definition and requirements established in section 2 into a concrete robotic system, while drawing inspiration from designs seen in the previous section on other grippers. Having selected the tendon-driven strategy over the pneumatic approach in section 2.3 , the goal is now to generate specific mechanical and electrical solutions that uphold the requirements listed in table 2.

### 4.1 System architecture

Figure 12: Left: An architecture where the actuator is placed externally. Right: An architecture where the actuator is placed internally to the end-effector

Designing a robotic gripper requires a holistic view of both the electronics and mechanics and how these interact. The system is a chain of subsystems going from control, activating drive electronics, actuating a motor that converts electrical energy to mechanical force, which is then guided down to a physical interface with the environment.

We have two main architectures we can choose from:

1. Displaced Motor: Fig 12 (Right side). In this configuration, the "heavy" actuation components are placed at the base of the robot or on a static platform. The force is transmitted to the end-effector via a transmission system (e.g., Bowden cables). This system saves weight on the gripper but has additional resistance from the transmission system. In a pneumatic or hydraulic system this resistance is almost negligible but in a tendon-sheath mechanism, the resistance is considerable as it is mainly governed by the Capstan equation (Foutput = Finput · e

µθ) [13]
which is an exponential relationship. The resistance can also introduce hysteresis to the system, due to the effects of static and kinetic friction.
2. Motor on End-Effector: Fig 12 (Left side). In this configuration, the motors, and potentially the drive electronics, are mounted directly on the wrist of the robot arm. This eliminates the resistance and hysteresis, but adds additional weight of the motor + electronics to the gripper. However, if the end-effector was to be used for other robot arms than the NRT-Lab arm, this would highly favor this architecture.

The benefits of having a motor on the end-effector made us look into lightweight motors. Picking a motor is a balance between weight, cost, power and performance. The ultra lightweight and compact motors, usually contain a limited amount of internal control and down-gearing, while also being quite costly.

An example could be the "Series 0816 ... SR" DC motor from Faulhaber [14], which are extremely lightweight (4.5 g), but with a low stall torque of 0.11 Ncm and a very high price point it is beyond the budget of this project.

We therefore went with the displaced motor architecture, since then we could use cheap servos with more power, integrated down-gearing, encoders, and internal control that could speed the development up.

### 4.2 Subsystems

As described in the previous section a tendon driven gripper generally consists of control → drive electronics → electromechanical actuation → mechanical transmission → and the physical interface with the environment (the fingers).

These parts of the systems can be put into separate subsystems, allowing us to make different conceptual designs of the subsystems, and put them back later in a modular way.

Page 13 of 70

4 CONCEPTUAL DESIGN | 4.3 Fingers and Bio-inspiration

Therefore we made five subsystems:

1. Fingers: This is the part that interacts with the gripped object. As specified in our prior work, this design concept leans up against the human hand, using tendons to actuate fingers.
2. Finger mount: The finger mount connects the end of the robot arm, the transmission line and the fingers
3. Transmission line: This is the transmission line that connects the actuator and finger mount.
4. Actuator: This subsystem involves the motors and the appropriate mechanisms for linking the motor rotation to tendon pull.
5. Control: The control subsystem involves choosing a control strategy -eg. how are the tendons moved relative to each other, and what variables control the movement (PWM, Current, position etc.).

We are now ready to make conceptual designs of the subsystems that uphold the requirements listed in the previous chapter. We start with the fingers.

### 4.3 Fingers and Bio-inspiration

To make the fingers, we use the bio-inspired design method. In our prior work we searched for grasping in nature, and found hands and tentacles and elephant trunks as our primary inspiration. We will now understand and transfer this into a design, that upholds the requirements from table 2.

Our design process initially focused on the human finger as the primary inspiration for the gripper’s structure and function. We chose this starting point because of its mechanical simplicity. While nature offers other flexible examples, like elephant trunks or octopus tentacles, we initially avoided these directions, fearing that mimicking their complex, continuous movement would result in a gripper that was too heavy and difficult to control. However, during the prototyping phase, we discovered a hybrid solution: we could utilize the simple, discrete joints of a finger-like structure to emulate the wrapping shape and behavior of an octopus tentacle. The following section details the iterative process that led to this insight.

Figure 13: A simplified schematic of the human finger. DIP is short for distal interphalangeal joint, and PIP is short for proximal interphalangeal joint.

Human finger-joint actuation

Figure 13 provides a simplified schematic of the anatomical components relevant to our design. The human finger consists of phalanges (bones), tendons that actuate the joints, synovium which functions as a lubricant, tendon sheaths that encase the tendons, and pulleys that anchor the sheaths to the bone. When tension is applied to the tendons, the force is transmitted to the phalanx. The pulleys constrain the tendon close to the bone, converting this linear tension into a rotational bending moment at the joint [10].

Human joints

Human finger joints are synovial joints, relying on fluid for lubrication and ligaments for bone-to-bone stability. While Liu et al. [10] successfully replicated this structure, the resulting design (Fig. 8) demonstrates the downsides of a strict 1:1 bio-replication strategy. The intricate assembly of individual components, mimicking every ligament and pulley, drastically increases both the fabrication complexity and the overall weight of the gripper, making this approach unsuitable for our goal of a lightweight gripper.

Page 14 of 70

4 CONCEPTUAL DESIGN | 4.3 Fingers and Bio-inspiration

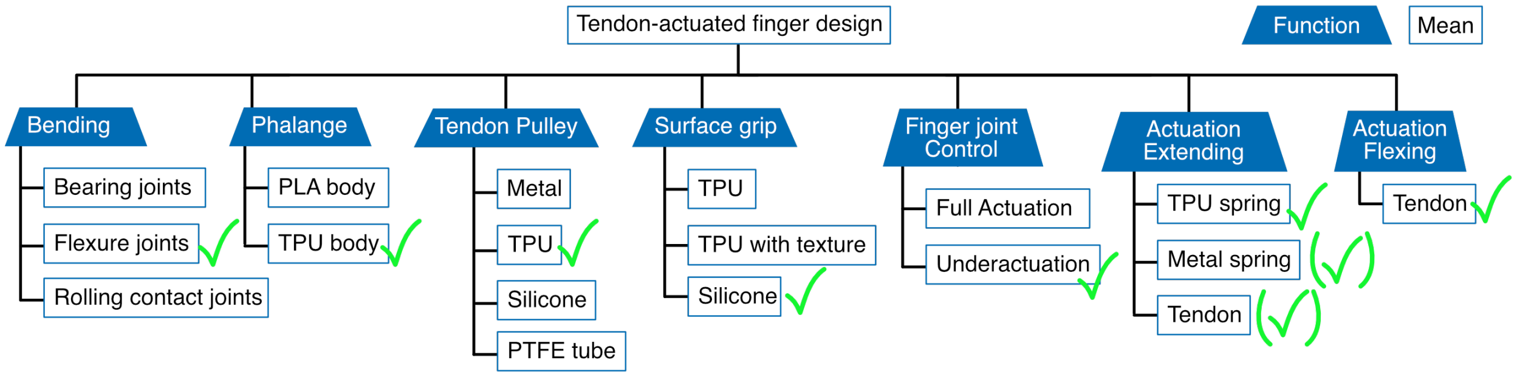
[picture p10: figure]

Figure 14: Function means analysis for the fingers. For clarity, the chosen means are already marked.

Functions

In contrast to Lui et al. [10], we abstract the finger functions to achieve a lightweight design. By mapping the biological functions into the function-means tree in Fig. 14, we identify the optimal means to mimic the finger’s functionality. For clarity, the chosen means are already marked. The rationale behind these design choices is detailed below.

Bending

The fundamental function of the finger joint is articulation. To achieve this, three primary means were considered. First, an anatomically accurate approach like Liu et al. [10], utilizing rolling contact joints with fabric ligaments. While bio-mimetic, the complexity of this assembly contradicts the goal of a lightweight design. Second, bearing joints, which are standard in robotics due to their low friction and large range of motion. However, the metallic components impose a significant weight penalty. Finally, flexure joints. Although these introduce elastic resistance and have a finite range of motion, they are superior for lightweight applications. This is because they rely on material compliance (elastic deformation) rather than complex mechanical assemblies.

Phalange

While the joints provide the necessary compliance to conform to objects (as discussed in Bending), the phalanges must address the opposing requirement: rigidity. As highlighted in the review of previous grippers, a purely soft structure risks lacking the strength to transmit force effectively or support internal components like pulleys.

To minimize weight and assembly complexity, we aim for a monolithic structure. Furthermore, to maintain the intrinsic benefits of a soft gripper, such as safety and adaptability, we avoid integrating completely rigid materials like metal or hard plastics. Consequently, we rely on a single soft material for the entire structure, accepting that this design choice involves a trade-off regarding maximum structural strength compared to hybrid designs.

Tendon Pulley

The tendon pulleys keep the tendon close to the bone so it doesn’t pull away when the finger bends. This ensures the pulling force is used effectively to curl the joint. To keep the design simple to make, we are using the same material for the pulleys as the finger bones, printing them in a single piece. While some prior works, such as Li et al. [11], employ PTFE tubes to minimize friction, we prioritize the mechanical simplicity of a monolithic design over the low-friction benefits of PTFE inserts.

Surface Grip

Page 15 of 70

4 CONCEPTUAL DESIGN | 4.3 Fingers and Bio-inspiration

Human skin balances durability with the softness to deform under load.
Cutkosky highlights that this surface deformation is essential for defining the contact conditions in robotic grasping [15]. To emulate this, we favor silicone over TPU for its superior softness and resulting grip. However, this choice introduces a durability trade-off: molding silicone onto the underlying TPU structure creates a multi-material interface that may be weaker and more prone to delamination or wear than a single-material TPU part.

Finger joint control

We can either fully actuate and control every joint, or choose under actuation for the fingers. Under actuation is the concept of having less degrees of actuation, than degrees of freedom. If we had full control of the fingers, each joint would require a tendon back to a separate motor. Two fingers with two degrees of freedom quickly becomes four motors, which would not comply with our requirements of simple control, and it would be harder to fit the transmission inside the soft arm.

Flexing and Extending

Human fingers employ antagonistic tendon pairs to actively control both flexion and extension. To minimize weight and control complexity, our first design iteration eliminates the extensor tendon, relying instead on passive extension. This strategy utilizes the elastic potential energy stored in the flexure joints during flexion to return the finger to its neutral position.

It is important to note that substituting active extension with passive material elasticity involves a functional trade-off. In an octopus-inspired morphology, relying solely on material stiffness can result in unwanted movement patterns or hysteresis. Furthermore, it does not resolve the conflict between compliance and strength (Fig. 11). Due to these limitations, we eventually developed a second iteration of the design that reintroduced an active extension tendon, a modification that will be discussed further in the embodied design chapter.

Figure 15: Principle structure of the finger joints

Figure 16: Principle function of finger joints

Other flexures and FACT (Freedom and Constraint Topologies)

Based on the functional requirements, we developed a principal structure consisting of rigid segments ("phalanges") connected by compliant flexure joints. As illustrated in Fig. 15 and Fig. 16, the tendon runs through the rigid phalange at a distance d from the neutral axis. When tension is applied, it generates a moment that bends the flexure.

To predict the behavior of these joints, we model the flexure as a cantilever beam (blade flexure) subjected to an end moment. The fundamental relationship for beam deflection is θ = −

M·L
E·I

[13]. By substituting the moment of inertia for a rectangular cross-section (I =

w·t

3
12 ) and the moment generated by the tendon (M = F · d), we derive the governing equation for the joint angle θ:

θ =

d · F · L · 12
E · w · t

3

Page 16 of 70

4 CONCEPTUAL DESIGN | 4.3 Fingers and Bio-inspiration

Where F is the tendon pulling force, d is the moment arm (distance from
flexure center to tendon), L, w, t are the length, width, and thickness of the flexure, E is the material’s Modulus of Elasticity.

Figure 17: Beam bending analysis of a blade flexure

This relationship highlights that the joint’s stiffness is cubic with respect to thickness (t). Therefore, tuning the wall thickness is the most sensitive parameter for adjusting the finger’s bending profile.

Flexure Topology and FACT Theory

The beam analysis above approximates bending stiffness but does not account for off-axis movements, such as twisting or side-to-side wobbling. To ensure the finger bends only in the intended plane, we utilized the Freedom and Constraint Topologies (FACT) method developed by Hopkins [16].

FACT analyzes how specific geometries constrain degrees of freedom. A simple blade flexure (Fig. 15) creates constraint lines that resists compression but offers little resistance to torsion along its vertical axis. To improve stability, we considered alternative topologies shown in Fig. 18:

- Cross Hinge: intersecting blades that eliminate the parasitic center shift of the rotation axis.
- Living Hinge: A thin, localized reduction in material.

While FACT assumes infinitely stiff and thin members—an idealization not fully achievable with soft materials, it provides the theoretical basis for selecting a joint geometry that maximizes bending compliance while resisting twisting moments during a grasp.

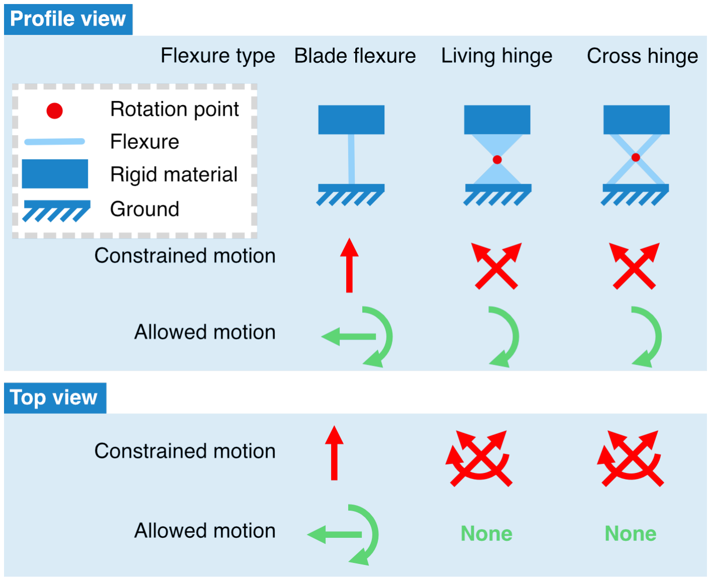
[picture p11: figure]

Figure 18: Three different flexures allowing rotational motion. Assumptions: Infinitely stiff and thin flexures.

Page 17 of 70

4 CONCEPTUAL DESIGN | 4.3 Fingers and Bio-inspiration

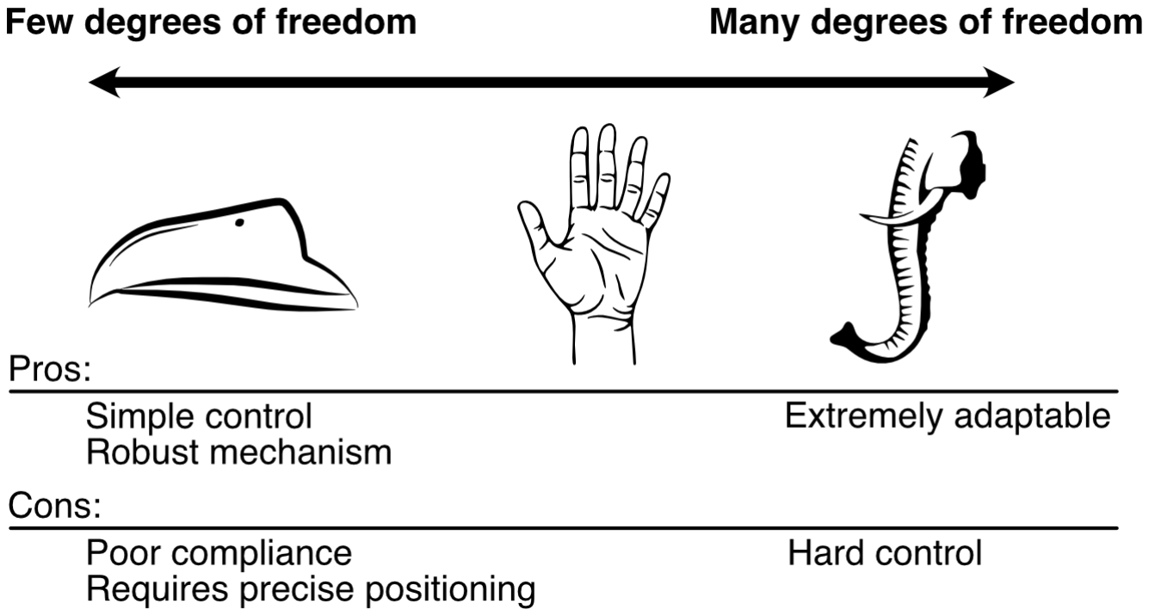
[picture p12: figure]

Figure 19: The Degrees of Freedom (DoF) Spectrum in Gripper Design Left: (Bird’s beak) 1-DoF systems prioritize mechanical robustness and simple control but offer limited compliance. Right: (Octopus) Many degrees of freedom provide high adaptability but increase control difficulty. Middle: The human hand represents a versatile intermediate, capable of multiple distinct grasp modes, due to the multiple fingers.

Bio-inspired morphology

As summarized in Fig. 19, the number of degrees of freedom (DoF) dictates a gripper’s functional trade-offs. Low-DoF biological mechanisms, such as a bird’s beak, provide rigid, precise pinching. Conversely, high-DoF structures, such as tentacles, excel at conforming to and wrapping around objects. The human hand occupies a versatile middle ground.

To achieve our goal of a compliant gripper, we prioritize the wrapping capability found in nature’s softest manipulators. Therefore, we move away from the rigid kinematics of the human hand and mimic the morphology of an octopus. Consequently, our conceptual design adopts the flexible, multi-jointed structure shown in fig. 20.

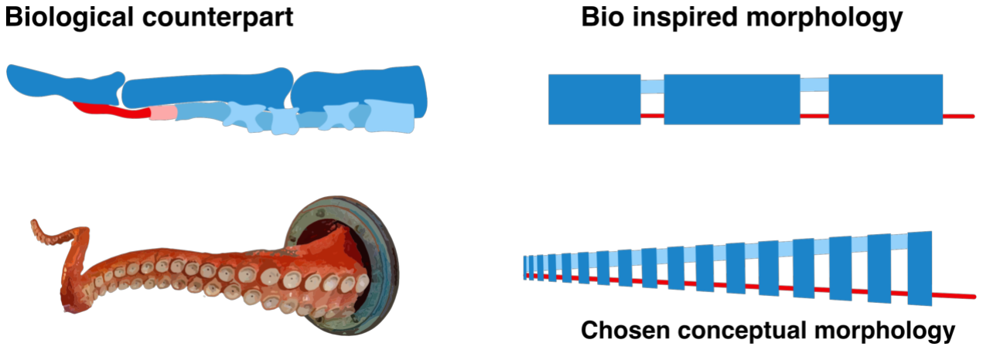
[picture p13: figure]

Figure 20: Bio inspired morphology

With the morphology and actuation strategy defined, the remaining challenge is anchoring these soft components to the rigid robotic system. The following section details the design of the Finger Mount, which serves as the interface between the soft gripper and the rigid robot arm.

Page 18 of 70

4 CONCEPTUAL DESIGN | 4.4 Finger mount

Figure 21: Function means tree for the finger mount

### 4.4 Finger mount

Now that we have made conceptual designs for the fingers, we now have to mount them, and connect them to the rest of the system. The finger mount has some functions it needs to perform. It has to be mounted on the end of the soft arm, it has to take the input of the transmission and distribute it to the fingers of the gripper. These functions are made into a function means tree in fig. 21.

Necessity of the finger mount

We will now argue on the necessity of the finger mount, as opposed to having fingers directly on the arm. If we had one transmission per finger tendon (and therefore did not need tendon distribution), we would have a bulky transmission that might not uphold the requirement from table 2, about fitting inside the NRT Lab soft arm.

The tendon distribution mechanism could be a simple knot as fig. 22 shows. This knot, however, needs some travel distance, from the fingers to the transmission, as it cannot go into the fingers. A quick estimation from one of our later prototypes was that 60 mm of travel distance was required. It is therefore necessary with this a separate finger mount subsystem, as we cannot mount the transmission directly to the fingers.

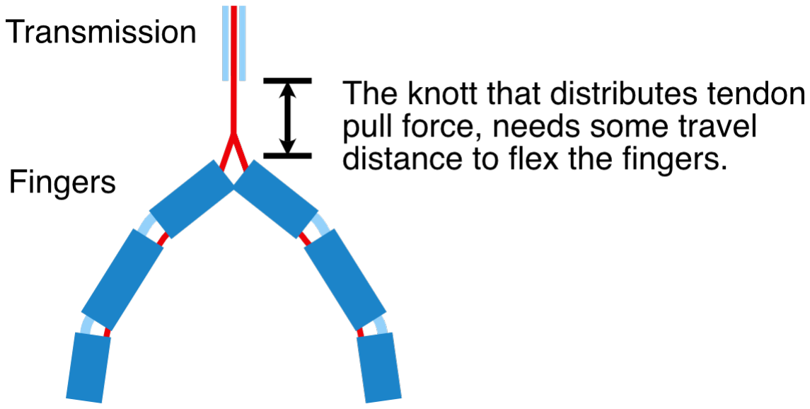
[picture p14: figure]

Figure 22: Tendon distribution travel problem

Tendon path considerations

The tendon path is the route the tendon follows from its origin at the motor spool to its termination point at the fingertip. Along this path, the ten-

Page 19 of 70

4 CONCEPTUAL DESIGN | 4.4 Finger mount

don passes through several regions of the system: first the actuator section, where tension is applied, then the soft robotic arm, where the tendon is guided internally; and finally the finger mount and the fingers themselves, where the applied tension is converted into bending motion.

For accurate and predictable actuation, the tendon path must be rigid from the motor spool up to the finger root, ensuring that any tension produced by the motor results solely in finger motion. If this section flexes or deforms, part of the tension is absorbed before reaching the fingers, leading to lost force and hardening the control task. Therefore, to prevent energy loss, the finger mount is designed as a rigid component.

Tendon distribution

The most critical function of the finger mount is tendon distribution, splitting the single input force from the actuator to multiple fingers while minimizing friction and weight.

We initially evaluated passive distribution mechanisms from the Yale Open-Hand project, specifically the floating pulley and whiffletree (visualized in the top row of Fig. 24).

While Ma et al. [8] suggest these mechanisms improve grasp adaptability by allowing fingers to close independently, our analysis indicated that they do not address the fundamental "travel distance" problem described in the previous section. These linear mechanisms require the same extensive housing length to accommodate the tendon stroke, failing to solve the packaging constraints of the soft arm.

To resolve this, we selected the rotational drum mechanism (Fig. 24, bottom). By wrapping the tendon around a spool, this design converts the necessary linear travel (60 mm) into rotational motion, drastically reducing the component’s footprint. Physical prototyping confirmed the superiority of this approach: a linear housing designed to accommodate the "knot" method weighed approximately 25 grams and was significantly bulkier than the compact drum prototypes. Thus, the drum offers the optimal balance of compactness and weight reduction.

Drum orientation

The orientation of the distribution drum (horizontal vs. vertical) dictates the gripper’s overall form factor and efficiency. This choice impacts three critical areas:

- Finger angle: The tendon should exit the drum tangentially and align directly with the finger. Any deviation creates friction points governed by the Capstan equation (Fout = Fine). While adding extra pulleys could correct this alignment, they would add unwanted weight.
- Finger distance: A vertical drum requires more space for mounting brackets and tendon routing. This forces a wider distance between the fingers compared to a horizontal setup.
- Finger quantity: As the tendon for the finger, should align tangentially with the drum, the vertical drum option can have many fingers around it without sacrificing friction, whereas having more multiple fingers on the horizontal drum, would sacrifice friction, if the fingers were to be in in the same plane of orientation.

Accommodating Two Tendons for the Second Iteration Fingers

To support the active extension introduced in our second design iteration, the tendon distribution mechanism was adapted to house two independent tendon lines. While this could be achieved using strictly horizontal or vertical drums, we utilized a hybrid combination of one vertical and one horizontal drum (Fig. 23). This configuration successfully accommodated multiple fingers within the compact housing, albeit at the cost of slightly increased friction due to some additional tendon routing.

Quantity of Fingers

The design of the end-effector requires a balance between finger count and weight. Increasing the number of fingers expands the range of available grasp modes, and makes a more secure grasp, it also adds weight. In our prior work, we found that three fingers are typically required to fully constrain an object, however, this assumes the fingers only have point contacts. A stable grasp can be achieved with only two fingers if the contact surface is sufficiently large. These wider contact areas allow the fingers to resist mo-

Page 20 of 70

4 CONCEPTUAL DESIGN | 4.4 Finger mount

ments, thereby providing the necessary stability while reducing the reduced
finger count.

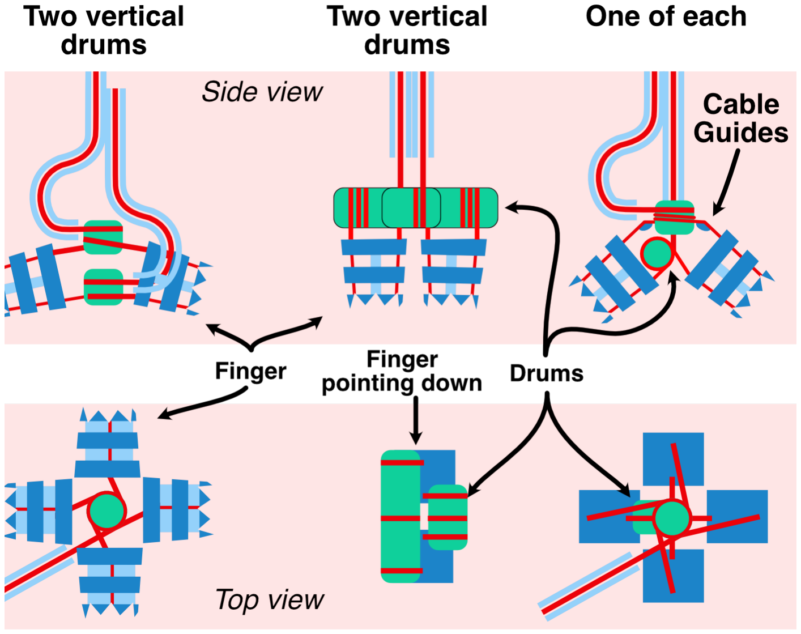
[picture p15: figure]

Figure 23: Drum orientation for two tendons.

Mountings

The finger mount serves as a central hub connecting three distinct subsystems. We evaluated the fastening methods for each interface based on weight, structural integrity, and ease of assembly/disassembly (serviceability).

- Finger Interface: As detailed in Appendix I, we explored various methods to secure the fingers to the mount. Based on our evaluation, the slot mechanism was selected. This design provides a lightweight connection allowing for rapid prototyping of fingers, and in the final prototype, a more modular solution.
- Transmission Interface: The connection to the transmission line was selected using a decision matrix (Appendix J), again prioritizing the potential for modularity by using a slot.
- Arm Interface: For the connection to the arm’s rigid end-plate, we opted for mechanical fasteners (screws). Due to the circular cross-section, implementing a slot mechanism would be difficult to align. Additionally, screws provide a rigid fastening method, ensuring better stability under load.

Functional surfaces

Functional surfaces are the specific geometries required to interact with other components. For the finger mount, these essential interfaces are:

- The drum interface
- The finger slots
- The transmission interface
- The arm interface

Any material outside these regions that does not contribute to structural integrity is considered excess mass. To systematically remove this dead weight while maintaining rigidity, we utilized Generative Design (Autodesk Fusion 360).

In this workflow, the functional surfaces were designated as "Preserve Geometry," while the tendon paths and rotating drums were defined as "Obstacle Geometry" to prevent material generation in these zones. The software then synthesized the optimal structure to connect these surfaces using iterative Linear-Static FEA [17]. A key advantage of this approach over traditional topology optimization is the integration of manufacturing constraints; specifically, we enforced a minimum strut thickness of 3 mm to ensure the resulting geometry remained stable during and after FDM printing.

We have now discussed the design concepts of the finger mount. In the next section we will move on the the connecting subsystem between finger mount and actuator: transmission.

Page 21 of 70

4 CONCEPTUAL DESIGN | 4.4 Finger mount

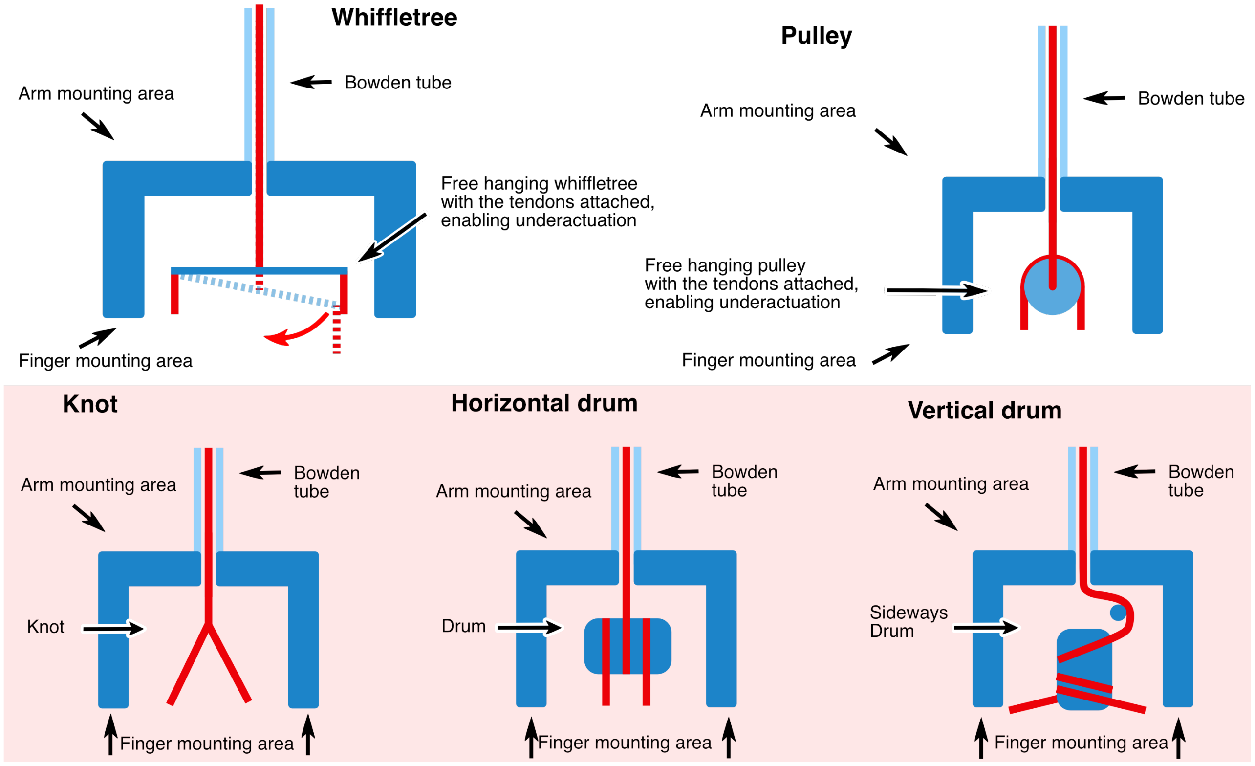
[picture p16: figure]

Figure 24: Different means for tendon distribution

Page 22 of 70

4 CONCEPTUAL DESIGN | 4.5 Transmission

### 4.5 Transmission

The purpose of the transmission is to transmit tendon pull from the actuator to the finger mount, where it will be distributed to the fingers. The primary requirement is to deliver this force with minimal energy loss to ensure the smooth operation of the gripper (as described in the previous "tendon considerations" section). It is therefore necessary to analyze the forces governing the transmission to minimize resistance. This mechanism is commonly referred to as a tendon-sheath mechanism.

The Capstan Equation

The governing principle of the transmission is the Capstan equation [13], which models the tension loss due to friction along a curved path:

Fin

Fout

= e

µθ

Where Fin is the actuator force, Fout is the resulting force at the finger, µ is the coefficient of friction, and θ is the total cumulative curvature (in radians). To maximize efficiency (Fout ≈ Fin), we must minimize both µ and θ. However, as the curvature θ is largely dictated by the pose of the soft arm, our design focus must remain on minimizing the friction coefficient µ.

Static friction inside the arm also introduces hysteresis; the static friction threshold must be overcome before the tendon inside the transmission can move relative to the sheath. This results in a "dead-band" behavior that is detrimental to precise control, further emphasizing the need for low-friction materials.

Axial Stiffness

In addition to friction, tendon elongation causes control issues. If the tendon has low axial stiffness (high elasticity), it will stretch before transmitting motion to the finger. This creates a spring-like hysteresis where the actuation of the finger is dependent on the loading history of the wire. Therefore, the ideal tendon must possess high axial stiffness (to prevent stretch) while maintaining high bending flexibility (to move smoothly through the sheath and the drums).

Component Selection

For the sheath, a PTFE (Polytetrafluoroethylene) tube was selected due to its flexibility and extremely low friction. PTFE is widely known as a "self-lubricating" solid, boasting a friction coefficient of approximately µ ≈ 0.02−0.2 against polished steel [18]. We utilized standard tubing common in 3D printing (2 mm ID / 4 mm OD) ensuring both low cost and high availability.

For the tendon, we selected an Ultra High Molecular Weight Polyethylene (UHMWPE) wire. This material exhibits high axial stiffness (negligible length change under load) while remaining flexible in bending. We selected a 1.5 mm diameter UHMWPE wire; this diameter fits with sufficient clearance inside the 2 mm PTFE tube, minimizing the risk of binding. Additionally, the thicker profile (compared to standard fishing line) provides a larger surface area, reducing the likelihood of the tendon cutting into the soft finger structure under load.

We have now defined the conceptual design of the transmission and will move on to the next subsystem, which revolves around creating the tension of the tendons.

### 4.6 Actuator

The purpose of the actuator module, is to provide motion and force, which is transmitted to the fingers. Since we are making the actuator module external to the gripper, we don’t really have any weight or size constraints which results in quite a lot of freedom when designing it. We will now go through some of the considerations we had concerning the actuator module.

In figure 25 we see an abstraction that helps us to understand the requirements of the actuator module. Everything located inside the red box, is defined as the actuator module. The control and feedback arrows will not be explained here, but in the next section (control section 4.7).

Page 23 of 70

4 CONCEPTUAL DESIGN | 4.6 Actuator

Figure 25: Abstraction of the actuator module functions. Control and feedback arrows are related to the control subsystem. The force is related to the transmission.

This leaves us with the motors, force interface to the transmission (tendons) and the power supply. In figure 26 we see a function-means tree with these functions. We will now explain these chosen concept choices.

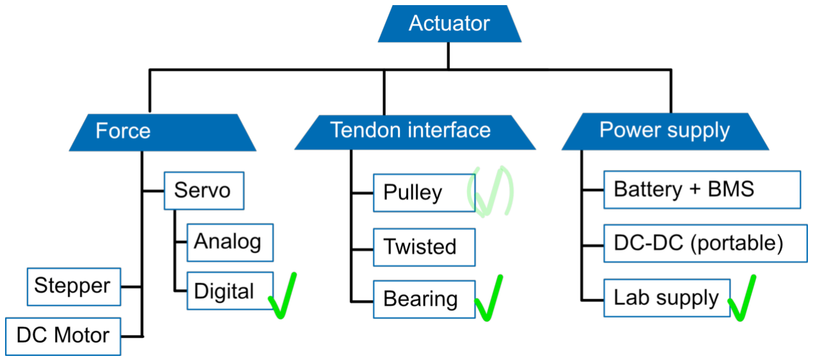
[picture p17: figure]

Figure 26: Function means tree for the actuator subsystem

Force and movement

As mentioned in section 2.3, we have chosen to use DC motors as the actuating basis of the gripper. As can be seen in the function means tree (figure

26), we have the choice between using "pure" DC motors, servo motors or stepper motors. Here "pure" DC motors are defined as a DC motor without any internal control, gearing and such.

The advantages of using "pure" DC motors are the low weight, size and high customizability. On the flip side they often don’t come with any encoders or internal control logic, which would require us to spend resources on the design of these parts ourselves. This is outside the scope of the project, and we will therefore not be using "pure" DC motors.

Both stepper motors and servo motors rely on some type of control electronics. Stepper motors use open-loop control and excel at very predictable and repeatable motions, by rotating in discrete steps. Servos use closed-loop control and gearing and are therefore usually better suited for achieving a compliant feel. [19].

These thoughts lead us to the choice of using servo motors. This choice resonates well with the chosen system architecture (external actuator subsystem), since weight and size is then less important. A future improvement could be the investigation of the use of "pure" DC motors, to enable incorporation of internal actuation in the gripper.

When choosing a servo motor for an external setup we need to balance performance and cost. An overview of a few different types of readily available servo motors in our price range is presented in table 3.

The candidate motors are sorted by increasing stall torque. The stall torque parameter is important to look at, since it is often listed in datasheets and it gives us an indication of the amount of force we can expect the motor to output. Stall torque is not a measure of the amount of torque to be expected under continuous operation, but a measure of the torque output at stalling conditions [20]. This means that we need to consider how long the forces are applied and needed. Eg. if we merely need to overcome some static friction for a burst of movement, it is okay to require torques close to the stall torque. However, if we need a constant high torque for eg. holding the grip, we need to stay below the stall torque, to ensure the continuous operation of the motors.

Page 24 of 70

4 CONCEPTUAL DESIGN | 4.6 Actuator
Model | Price [C] Weight [g] Stall Torque [Ncm] Supply [V] Control level
TowerPro SG90 | 5 | 9 | 11-15 | 4.0-6.0 | PWM signal (angle), internal analog control
XL330-M288-T | 40 | 17 | 42-60 | 3.7-6.0 | Advanced internal MCU control, (current)
Towerpro SG-5010 | 10 | 47 | 54-64 | 4.8-6.0 | PWM signal (angle), internal analog control
XC330-M288-T | 131 | 23 | 69-110 | 3.7-6.0 | Advanced internal MCU control (current)
ST3020 | 24 | 99 | 145 | 6.0-14.0 | Internal MCU control (current)
XL430-W250-T | 43 | 57 | 100-150 | 6.5-12.0 | Advanced internal MCU control

Table 3: Comparison of different servo motors that we considered during servo motor research.

The other performance factor that must be considered, is the "control level"
- meaning the amount of internal control already implemented in the servo. In general we can split the servos into two categories: simple analog control and more advanced digital control. The first category works by using an analog circuitry to map the duty cycle of a provided PWM signal to an angle of the shaft encoder - simple and cheap [21]. However, as mentioned before, it is desirable for us to use a motor with as much internal control already implemented - both for the rapid prototyping and for the testing of control concepts. We will therefore turn our attention to the motors marked with "internal MCU control" in table 3.

We now have a choice between the brand Dynamixel (XL330, XC330 and XL430) and Waveshare (ST3020).

In our research, we found that the Dynamixel motors have a solid ecosystem of hardware, firmware libraries, testing software and documentation. Eg. the combination of the testing software "Dynamixel Wizard 2" [22] and the "Dynamixel U2D2" computer adapter [23] enables a quick working testing setup where the motors can be manually controlled and monitored. Furthermore, the Dynamixel motors support a wider range of different operation modes than the Waveshare, such as; Position mode, Extended Position mode, Current mode, Current based Position mode, Velocity mode and direct PWM (voltage, not angle) mode.

Figure 27: Screenshot of the Dynamixel Wizard 2.0 [22]

The above considerations lead us to the choice of buying a set of both the Dynamixel XL330-M288-T and the Dynamixel XL430-W250-T for testing and developing. The difference between these motors is mainly the size and hence also the stall torque rating. The XL430 servo is the bigger and stronger, and the XL330 is the smaller - we chose these two motors with different torque ratings, because in the beginning we did not know the exact amount of actuation force needed. The reason for not just picking the big (XL430) high torque servo right away, is because the small (XL330) servo is able to use current as a control parameter - which is very well suited for achieving a compliant feel of the gripper. Physically, both Dynamixel servos communicate over a TTL serial half-duplex connection.

Page 25 of 70

4 CONCEPTUAL DESIGN | 4.6 Actuator

We now have a good starting point for developing the actuator module;
namely two motor options to experiment with. We will now continue to look at the interface between these motors and the tendons that actually actuate the fingers.

Tendon interface

In the last paragraph, we analyzed the choice of servo motors. Now we will move on to the interface between these motors and the transmission -specifically the interface between the rotational movement of the motor and the linear motion of the tendon inside the transmission. We will now briefly go through a couple of different concepts (seen in figure 28) capable of connecting these two motions.

The first method that we would like to highlight, is using twisting tendons. This alternative design involves attaching two parallel tendons (orthogonal) to the horn of the servo. When the servo rotates, these will twist around each other, and result in a linear displacement of the end points. This design can e.g. be seen in figure 10 (Bombara et al. [12]), where a soft robot hand is actuated using "pure" DC motors and twisted tendons. The downside to this, is the fact that you have to fit two tendons inside the transmission, and that you usually need a bit of space for the tendons to twist/untwist.

Figure 28: Principal structures of the interface between servo motor rotational movement and actuating linear movement

The second and maybe most known concept is a pulley directly mounted to the horn of the servo motor. This concept is simple and with only a single part enables the required translation of movement. The downside of this setup is the structural radial load on the axle, potentially stressing the inner structure of the motor.

To overcome the issue of stressing the servo motor with a radial load, one could further develop the pulley interface by using an external axle resting in a grounded bearing house. This ensures that the servo motor only ever sees tangential loads, and that the radial loads from the tendons get transferred to the strong(er) bearings. This second concept does introduce more parts and therefore increases implementation complexity - but because of the external actuator placement, this is acceptable.

Initially we picked the simple pulley solution, but as we will see in the embodied design, we pivoted away from the simple pulley and towards the bearings, to spare the axle of the motor from the radial stress.

Power

The last function in the actuator module is the the power supply to the motors. Since we have chosen the Dynamixel motors XL330 and XL430, the voltage of the power supply should be either 5 or 11V (see table 3). We could use a small DC-DC converter board to power the electronics, or even use a battery to make it portable. However, the main focus of this project is not a finalized product, but a first prototype, meaning that the power source will most likely be the least prioritized optimization task. This means that we will stick to using a variable lab power supply for most of the developing and testing of the gripper.

This brings the section of conceptualizing the actuator subsystem to an end. In the next section we will discuss the input and output of the actuator: control and feedback.

Page 26 of 70

4 CONCEPTUAL DESIGN | 4.7 Control

### 4.7 Control

The purpose of the control subsystem is to have a way of communicating with the actuator module. This communication enables us to develop and test the gripper. It is not the goal to have a final (physically) miniaturized control system - however this would be the obvious next step after achieving a rough first prototype. For now we will go through the different concepts of the control, which we have worked with in the project.

Hardware

The first thing to consider when designing the control system is the physical framework (hardware) that hosts the firmware that controls the gripper. This framework needs to be fast to prototype on, and ideally include proper documentation and a community-driven support system. Apart from communicating with the actuator module, it should be able to connect to various devices/sensors that we might need - e.g. a UART port for live debugging between the hardware and our computer. If we need to satisfy these requirements, the most obvious concept is a development board with a micro controller, GPIO pins and power supply. Below is a list of some of the many boards that satisfy these needs:

- Arduino Boards
- ESP32
- STM32
- Teensy
- (OpenRB-150)

These development boards all more or less satisfy our needs, and the factors of availability and cost end up determining our choice. The fact that we have multiple Arduino UNOs available already and that we are used to developing on these, means that we will use the Arduino UNO for the control hardware. (Note: the OpenRB-150 is very well suited for controlling the Dynamixel motors, but would increase the cost of the project. For a future improvement of controller size and performance, using the OpenRB-150 micro controller would be the obvious choice).

As mentioned in section 4.6, the Dynamixel motors use a half-duplex serial connection. Since the Arduino UNO uses a full-duplex UART, this means that apart from the Arduino itself we need to use a full-to-half-duplex interface between motors and micro controller - which exists in the form of a shield for the Arduino UNO.

The last addition to the micro controller itself, is a separate UART to USB debugging tool. We need this separate UART since the UART connected to the USB port of the Arduino UNO is used for the Dynamixel bus. So for simultaneous use of the debugging port and motor communication we need the extra UART to USB.

Signal pathway

The Dynamixel motors communicate using the Dynamixel Protocol 2.0 (via the UART TLL Half-Duplex connection) [24]. This protocol is the backbone of communicating with the motors, and enables us to set up the motors, command them and retrieve information about them. The protocol relies on the instruction packet structure and response (status) packet structure seen in tables 4 and 5, respectively.

Header | ID | Length | Instr | Param | CRC
4 bytes | 1 bytes | 2 bytes | 1 bytes | Variable | 2 bytes

Table 4: Principal structure of a Dynamixel Protocol 2.0 packet [24]

Header | ID | Length | Instr | Error | Param | CRC
4 bytes | 1 bytes | 2 bytes | 1 bytes | 1 bytes | Variable | 2 bytes

Table 5: Principal structure of a Dynamixel Protocol 2.0 status package [24]

To ensure fast responsiveness in the control and reliable real-time testing data acquisition, we want to limit the amount of time spent communicating on the Dynamixel bus. Therefore we will take a look at how the Dynamixel

Page 27 of 70

4 CONCEPTUAL DESIGN | 4.7 Control

bus works. As can be seen in table 4 the total size of the instruction packet
is 10 + Ninstr bytes, where Ninstr depends on the instruction sent, since the parameters will vary from instruction to instruction. Likewise, the total length of the status packet (the response) is 11 + Nstatues bytes.

The transfer time of requesting and reading motor data depends on the speed of transfer as well as the size of the data. The Dynamixel motors support up 4 Mbps of data transfer rates, however, the Arduino UNO does not support such high data rates. During initial research and prototyping, we found that a transfer rate of 1 Mbps balanced speed and stability. Hence, we have chosen a transfer rate of 1 Mbps. Since the Dynamixel Protocol UART uses 8-bit, 1 stop/start bit, no parity setup, the effective UART transfer speed (reff) of data in bytes/second can be calculated like this:

reff =

bits/s
bits/byte =

1 ∗ 10⁶bits/s
(8 + 1 + 1) bits/byte = 100, 000 bytes/s | (1)

So when transferring data we end up with a transfer rate of 100, 000 bytes/s. If we now look at the sequence of transfer in the Dynamixel Protocol 2.0 (see figure 29), we see that the total transmission time includes a small delay between request and response (Return Delay Time, RTD), which is implemented by the motors.

Figure 29: Time frame showing the different things affecting Dynamixel Protocol communication [24] (screenshot)

The purpose of RDT, is to avoid data corruption of the status packet (response), by avoiding bus collision. By default, the RDT is set to 500µs in the

Dynamixel motor registers. To avoid messing with the timing on the bus, we keep the RDT unchanged. However, if higher transfer speeds were needed, the RDT value could be altered in the future.

Firmware design

The next concept to deal with in terms of controlling the gripper, is the actual code running on the micro controller and commands to the motors. We will now take a look at this part of the project.

To ensure smooth development and operation of the gripper, unity between program state and actual (physical) gripper state is important. Among other things, this includes accuracy and speed - which are linked together. A fast sampling of the physical state helps to achieve a high accuracy of the program state. Fast state sampling also enables the possibility to filter the current state, with less of a delay. To ease the coding and debugging of the gripper, we should ideally implement a state machine, that keeps track of the internal state and state transitions.

To solve the issue of bridging code running on a micro controller to real life state, robots are usually kinematically modeled. In soft robotics, the kinematic modeling is different from rigid robotics. Webster et al. [25] review the current techniques of modeling continuum robot arms using constant curvature kinematics, which might be of interest if we needed a model. Another example of correlating robot state and control is found in SpiRobs, where the effects of frictions from tendons are modeled [4]. In the scope of this project, we will not create a virtual inverse kinematic model of the gripper, but instead see how good of a performance we can achieve without any modeling, due to requirement of having a low control complexity.

On top of keeping track of internal state, grippers ideally need to be used and controlled by other robotic systems. This is usually done by designing an interface between the gripper’s control system and the outside control. Many different communication protocols exists in the industry. Since this gripper would always be mounted on a robot arm, a wired interface makes the most sense. To name a few possibilities in our use case: CAN, SPI, I2C or RS-485 [26, 27]. However, because of the scope of the project, we will focus on a simple internal interface for now (button or timer). In a future version, the

Page 28 of 70

4 CONCEPTUAL DESIGN | 4.7 Control

addition of an industry standard interface protocol could be added, for better
integration into a full robotic system.

Perhaps the most interesting part of the control subsystem is the actuation strategy implemented through the state machine. This will be the next thing we go through.

Actuation strategies

Actuation strategy is the way in which we actuate the tendon(s) in the gripper. This includes how many tendons we use, and the relative movement/force of the tendon(s) to each other. As mentioned in the conceptual design section of the finger (4.3), we most importantly need a flexing tendon, as this enables the grasping of object. There are two main reasons for adding an extensor tendon. If the passive extension of the fingers doesn’t work, an extending tendon is also needed. And also, and maybe most importantly, as we learned in the beginning of the report, adding an antagonistic extending tendon can increase the stiffness of the structure.

In light of the control subsystem, there are three interesting aspects of the actuation curves: The type of control variable, the control signal curve and how that curve is sent to the actuator. By control curve we mean a control variable (e.g. PWM/position/current), that is changing over time - depicted as a curve. As mentioned in the beginning of the report, previous soft grippers use different strategies for grasping. In figure 30 we see some different types of control curves. The control variable (y-axis) can be things like motor voltage (PWM), motor current or motor position, depending on the gripper that is implemented. Having so many possibilities of choosing a control variable, resonates well with the discussion of having many operation modes available in the servos.

The choices we can make in terms of control curves are:

- Control variable
- Single vs. Dual tendon
- Symmetric vs Asymmetric
- Single vs Multi-stage

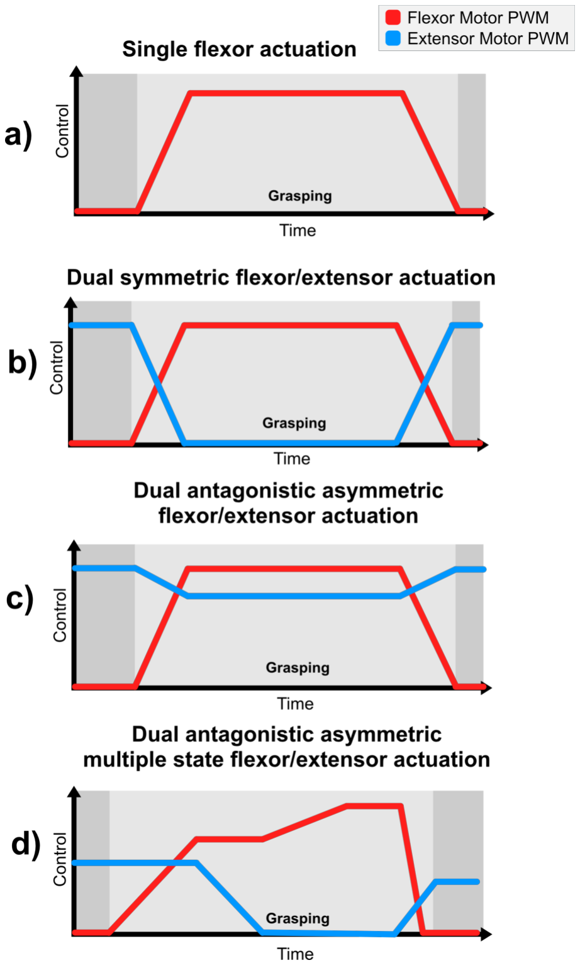
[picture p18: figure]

Figure 30: Sketches of conceptual actuation strategies. a) Simple single flexor actuation. Only the flexor is actuated here. b) Here both flexor and extensor are actuated in opposite, but symmetric curves. c) Again both flexor and extensor tendons are actuated, however, here the extensor applies an amount of tension against the flexing movement - resulting in an antagonistic movement. c) Both flexor and extensor tendons being actuated. The difference is that there are more stages than in the other strategies.

Page 29 of 70

4 CONCEPTUAL DESIGN | 4.7 Control

These differences balance implementation complexity and performance, and
their strength depend on the final morphological implementation. Eg. if one is trying to achieve an alive/curious feel of the gripper like the one seen in SpiRobs [3], the fingers should be actuated using antagonistic torque and the advanced control curve seen in figure 30 d), whereas if we just need a simple grip action [6, 8] we can use the position variable and control curve a) or b). We will discuss the final choice in the control section of the embodied design (5.6).

The practical question of transmitting the control signals to the motors also depends on which control curve, and specifically which control variable, is chosen. The internal control in the Dynamixel motors allows for defining custom position and velocity trajectory parameters, which can be used to realize control curves like the ones in figure 30 a)-d). Then it is just a question of sending position commands to the motors simultaneously at the right times and the Dynamixels will generate the curves - resulting in the desired movement. However, if we want to implement control using motor current or voltage (PWM), we need to construct these curves on the controller and transmit the correct control value at each instance in time.

This is the end of the control section, and thus also the end of the conceptual design as a whole. We have now laid out the concepts that are crucial to consider in the prototyping stage of the project: embodied design.

Page 30 of 70

5 EMBODIED DESIGN

## 5 Embodied design

We are now ready to embody the conceptual designs from the previous section into actual physical structures. This is an iterative process, and through continuous refinements in each version, we converge on the final design of the gripper. This development process is described in the following.

### 5.1 Development of test platform

The first "prototype" we developed, was a small testing platform (figure 31), that enabled us to do some initial testing of both the actuation, control and finger structure. It was great for a quick start and sparking the intial ideas. This test setup was later replaced, when we started building the final prototype, since we weren’t able to test the transmission and finger mount properly on the test platform.

Figure 31: Test platform that we used for initial actuator and finger testing. The fingers can be slid in and quickly changed. The platform features a grid of small holes, where other objects can be fastened with M2.5 screws.

### 5.2 Fingers

As in the conceptual design, we start with the prototyping of the fingers. On the basis of the conceptual design we will in this subsection prototype and create a detailed design of the fingers for our gripper, with our human finger inspired principle function and octopus inspired morphology. The functionmean tree for the finger functions (Figure 14) gave us the relevant functions with different means to perform these function. In the following we want to detail these means, which leads to the making of several different prototypes.

Design and testing of joints

The flexure joints is the most important aspect, as it enables bending, and therefore we prototype the flexure joints first. We want our flexures to have low internal resistance and be stable. To find flexures living up to these requirements we prototype the flexures mentioned fig. 18 and they can be seen in fig. 32.

Figure 32: Left: The first iteration of blade flexure joints. Right: The first iteration of living hinge and cross flexure joints. Top row shows living hinges. Bottom row shows cross flexures.

After testing the flexures by actuating them by hand, we made these findings:

- Living hinges: plastically deformed when actuated too many times, since all the stress was concentrated at one point. The springiness of the flexure were extremely slow, this can be seen in fig. 34
- Blade flexures: worked well, and we decided to test them using the test setup in fig. 33 and the results in table 6 showed that shorter and thinner flexures were more stable and has less internal resistance.
- Cross flexure: In figure 32 we can see the cross flexures on the bottom row. The cross flexures showed best springiness out of the three, which can be attributed to the extra material in which the stress can

Page 31 of 70

5 EMBODIED DESIGN | 5.2 Fingers

distribute inside the flexure. And we validated that they worked well by
testing with the setup in fig. 33 giving us the results in table 7

Figure 33: Blade flexure test setup for finding the effectiveness of the joints. The output newton meter is taped to the table to ensure, it is grounded and the only changing variable is the force applied with the input newton meter.

Length | Thickness | Input Force | Output Force | Notes
20 mm | 2.0 mm | 10 N | 1.0 N | Stable
20 mm | 0.8 mm | 10 N | — | Buckling
10 mm | 2.0 mm | 10 N | 1.3 N | Stable
10 mm | 0.8 mm | 10 N | 1.6 N | Stable

Table 6: Blade flexure test results.

Length | Thickness | Input Force | Output Force | Cross Angle
5 mm | 0.8 mm | 10 N | 1.2 N | 32.5◦
10 mm | 0.8 mm | 10 N | 1.5 N | 57.2◦
5 mm | 0.8 mm | 10 N | 1.3 N | 61.3◦

Table 7: Cross flexure test results.

We also did some initial tests of the springiness of the flexures (fig. 34, and

found some problems:

1. TPU is a viscoelastic material. Material properties are time dependent, i.e. if a gripper is closed for a long time it would, take longer than normal to open again, this showed in our tests. This reduces the reliability of using the flexure joints as springs.
2. A flexure with more angular stiffness makes the flexure revert back to the original position faster and more reliably. It also makes the problem of viscoelasticity less obvious. More angular stiffness will however need a higher force to actuate the flexure.

Figure 34: Testing the extension of the flexures, by fully loading the flexures, and checking the recovery 5 seconds after being loaded. The cross flexure showed the best extension capability.

Page 32 of 70

5 EMBODIED DESIGN | 5.2 Fingers

To fix these problems we made a metal flexure finger (Appendix K) getting
rid of these problems, but it did not get rid of the problems we will describe in the following.

First iteration gripper prototype

Using the results from above we made a gripper prototype utilizing the cross flexure for its superior extension, and for its ability to resist torsion (fig. 18). Using the test platform, and actuators we made some initial tests (fig. 35. The principle function from fig. 15 and principle function from fig. 16 worked great, but the choice of mimicking the morphology of the octopus to get a soft wrapping gripper did not work.

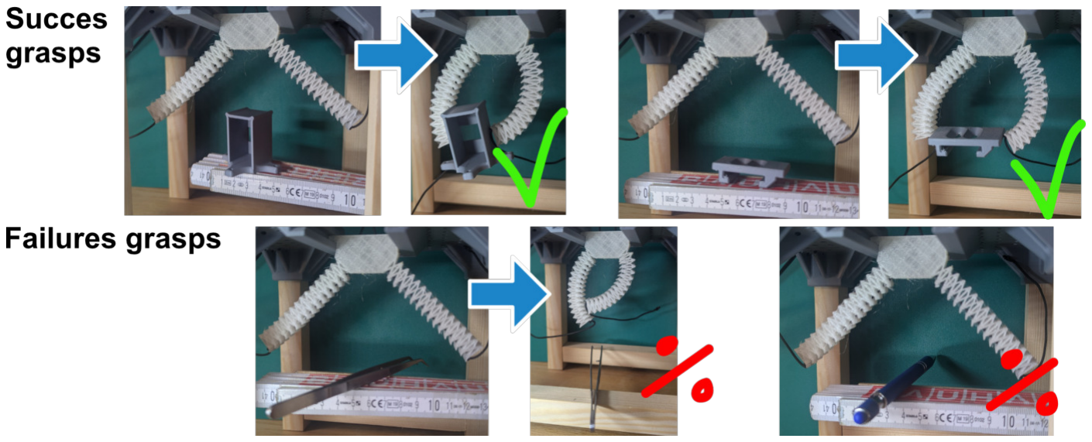
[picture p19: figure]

Figure 35: Test fingers of first gripper. Embodied version of the chosen concept in fig. 20

When flexing the gripper, it bended with an almost constant curvature, all the joints at once, causing no wrapping of the objects. As mentioned previously, an octopus grasps around an object by enveloping it by bending the arm joint by joint around the object to wrap it - following the logarithmic spiral. This together with the fact that this prototype did not address the balance between compliance and strength (fig. 11), made the grasping unreliable and only able to lift very light loads (maximum ca. 20 grams).

Dual actuation

With the findings from above in mind we prototyped tendons as a means to extend the fingers. Having two tendons also allows us to increase the stiffness by applying antagonistic forces. The mathematical model of a antagonistically tendon-driven robot by Wang et al. [4], tells us that by antagonistically actuating the finger, we can also actuate each individual joint one by one, due to the friction inside the tendon pulleys.

Our fingers with cross flexures buckle under these antagonistic forces (fig. 36). The FACT design methodology assumes infinitely stiff and thin flexures, i.e. the flexures are assumed to not buckle [16].

Figure 36: A finger with many cross flexures buckling under antagonistic actuation.

Figure 37: Using two tendons to control one finger.

Page 33 of 70

5 EMBODIED DESIGN | 5.2 Fingers

Morphology

The example in fig. 37 appears to conform perfectly, however it is unreliable and does not always do that. To understand why we looked into the paper from Wang et al. [4], which modeled this kind of robot using the Capstan equation ( Fin

Fout

= e

µθ). They found that the movement pattern of the robot is dependent on tension distribution inside the robot and its history.

Figure 38: A fully extended finger with a non-spiral morphology. This finger would hit the finger mount, not being able to fully extend, and therefore act unpredictably.

When the finger in fig. 37 is fully extended, it collides with itself, creating an unpredictable next movement of the finger (as seen in fig. 38. To mitigate this problem we look at the octopus, and we find that the octopus curls it tentacles up and stores the tentacle in a logarithmic spiral, enabling them to uncurl their arms around an object.

We want our robot in a fully extended position to have the shape of a a logarithmic spiral. We therefore modeled our finger after the spiral as seen in figure 39. The spirals are generated from the general formula for a logarithmic spiral [28]:

⃗s(θ) = aebθ
cos θ
sin θ
(2)

The finger consists of a central spiral with parameters a = 9 ∗ 10⁻³ and b = 0.2. The inner/outer spirals (blue in the figure) are scaled versions of the central spiral (kscale = 0.5).

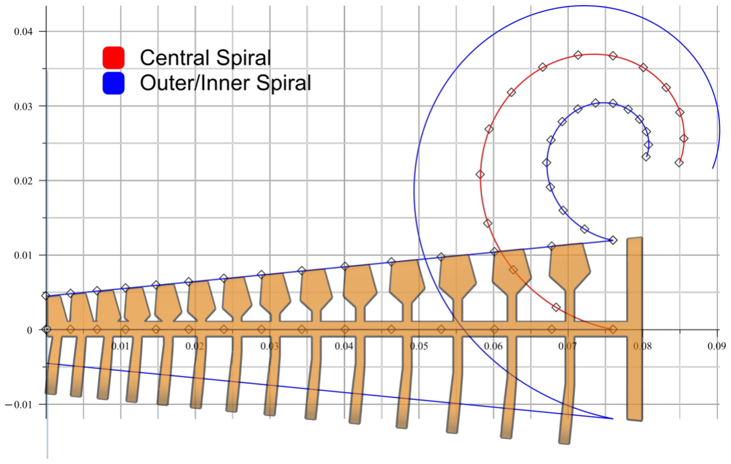
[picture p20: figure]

Figure 39: Depiction of the logarithmic spiral and points along its curve, spaced with equal increments in angle θstep = 20◦

. The spiral is "unfolded" and the points of the increments are used as a guidance for the finger joint design.

The points ((px, py)) of the curled up spiral are determined with the formula for the arc length of a logarithmic spiral (starting in θ = 0, which is determined by the line integral of formula 2), as well as the radial straight-line distance between two equal (angle) points (θcentral = θouter) on the central and outer spiral:

px(θ) = arc(θ) = a ∗

√
1 + b

2
b

∗ (e

bθ − 1) | (3)
py(θ) = |⃗souter(θ) − ⃗scentral(θ)| | (4)

This point is then calculated 15 different times, with an increment of θ = 20◦ per point. Worth noting is that this point calculation does not preserve exact geometric thickness, but it maintains the exponential growth inherent to the logarithmic spiral. As a result, we can use the unfolded curve as an approximating template for the design of our finger. The final finger design can be seen in fig. 40 and the octopus inspired motion in fig. 41.

| Page 34 of 70

5 EMBODIED DESIGN | 5.2 Fingers

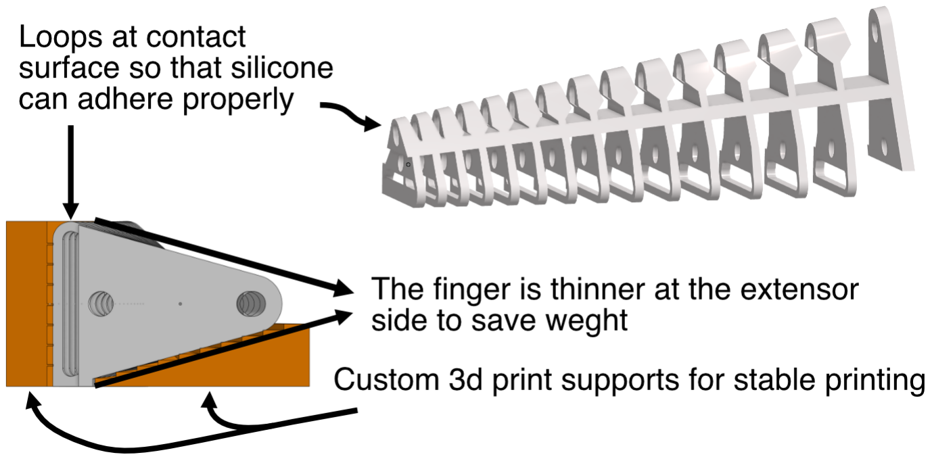
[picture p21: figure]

Figure 40: Final finger design. The custom supports enable better printing in TPU, while still saving weight from the tapered angle.

Figure 41: The octopus inspired wrapping behavior of the gripper

Design and testing of the contact surface

For the contact surface we prototyped both with and without silicone on the final finger and found that applying silicone dramatically increased load the load the gripper could carry. To make the silicone adhere properly, we created holes where the silicone would be, so the silicone did not have to rely solely on adhesion, but also on its own structural integrity. Applying the silicone to the gripper could be done in to ways. We could mold the silicone around the finger inside a form, creating a thick solid layer. This takes some time and needs tooling but is fairly robust. We could also dip coat the finger in silicone. This creates a thinner and more uneven layer, but is fast and does not require tooling.

Figure 42: Different techniques to coat the finger in silicone. Top: Custom mold, Bottom: Dip coated silicone.

Fingertip

The current embodied design utilizes a manual knot to secure the tendons at the fingertip. While this approach minimized the complexity of the initial prototype, it introduced challenges regarding the calibration of the tendon lengths. Furthermore, the optimal geometry for the fingertip remains to be determined. As the current finger morphology is primarily designed for wrapping as seen in fig. 41 rather than pinching, the fingertip shape was not a priority in this the final design. However, future development should investigate fingertip geometries to enhance the gripper’s ability to pinch.

Page 35 of 70

5 EMBODIED DESIGN | 5.3 Finger Mount
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

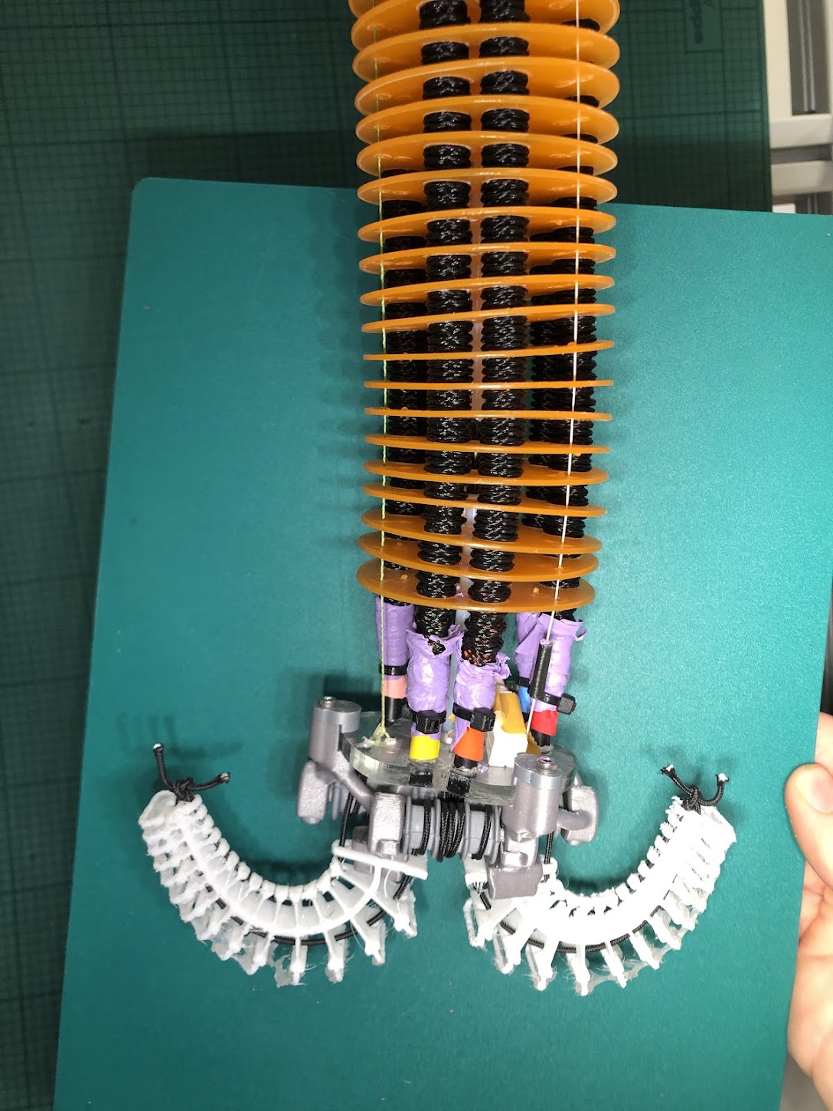
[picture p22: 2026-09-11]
gripper.jpg

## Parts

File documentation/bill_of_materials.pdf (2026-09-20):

G BILL OF MATERIALS

G Bill of Materials

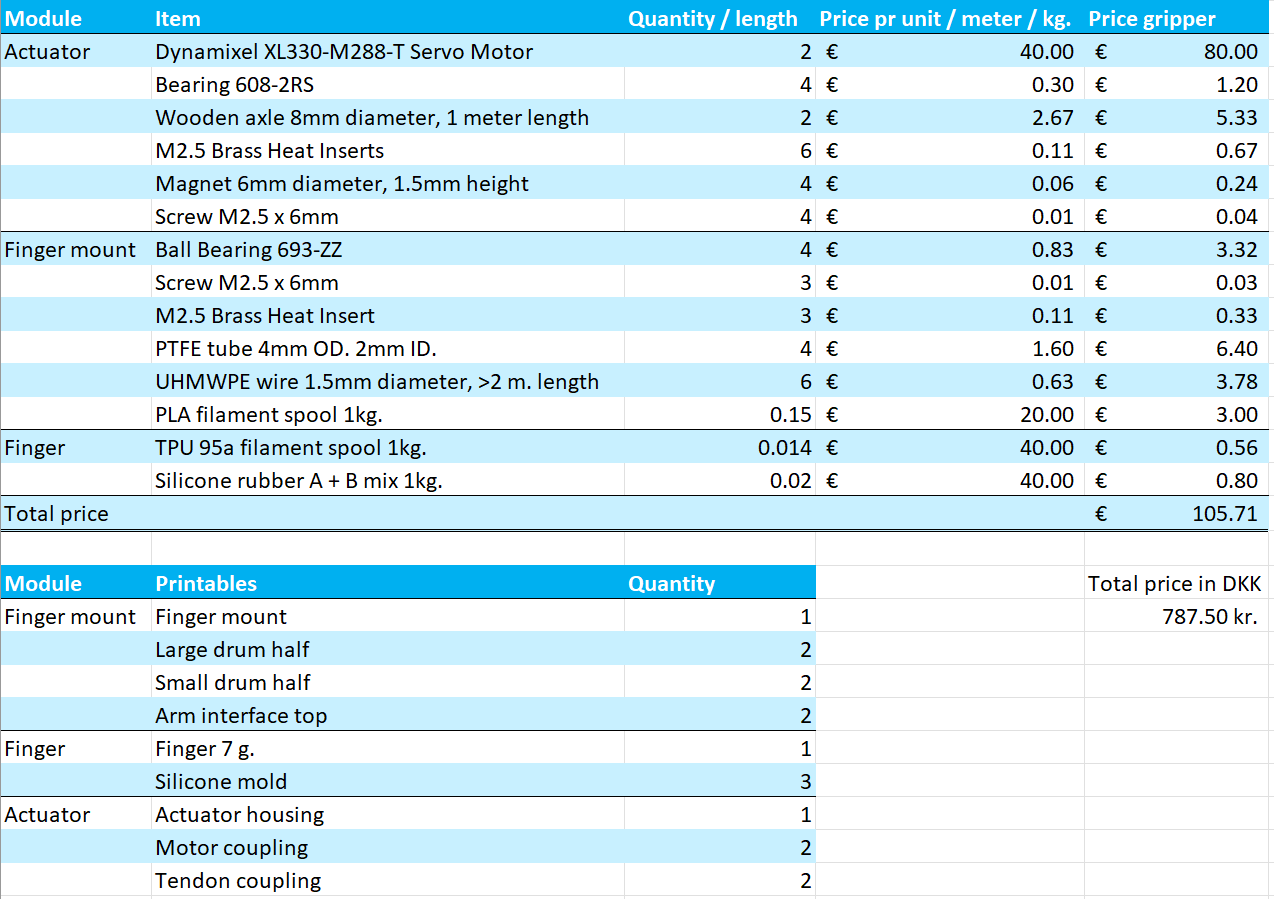
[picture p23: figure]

Page 65 of 70

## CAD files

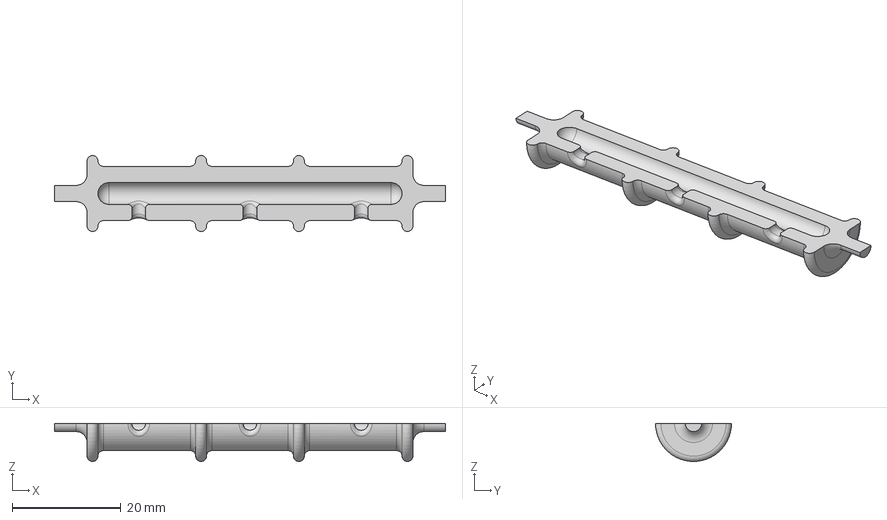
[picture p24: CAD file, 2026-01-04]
3d_files/Finger mount - Large drum half.step
72.0 x 14.0 x 7.00 mm

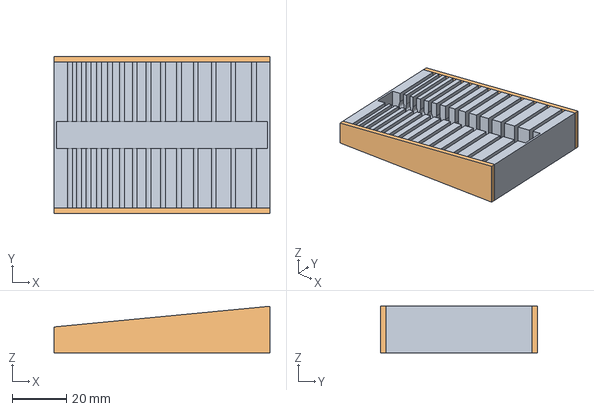
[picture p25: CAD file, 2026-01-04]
3d_files/Finger mold.step
79.6 x 58.0 x 17.1 mm

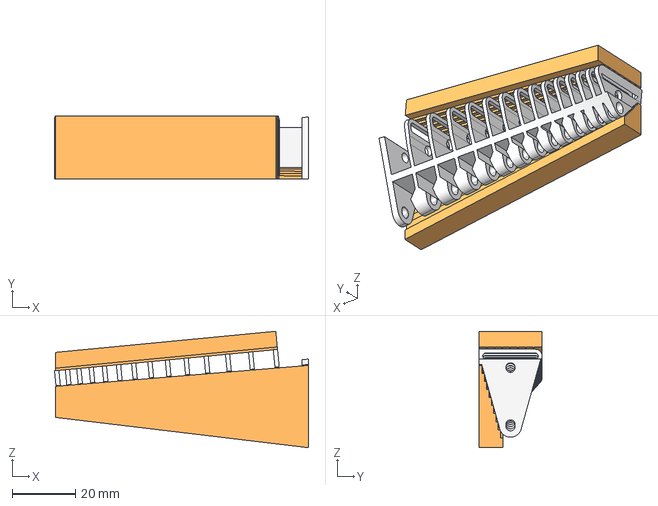
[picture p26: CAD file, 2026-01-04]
3d_files/Finger - with supports.step
80.2 x 20.0 x 36.8 mm

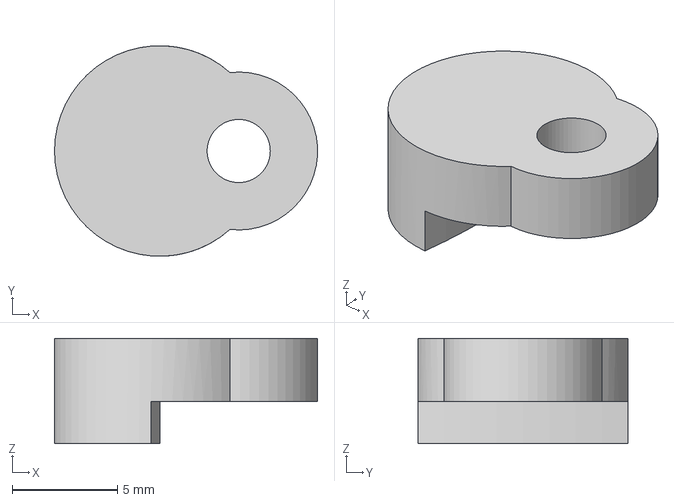
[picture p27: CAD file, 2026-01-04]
3d_files/Finger mount - Arm Interface Cap.step
12.5 x 10.00 x 5.00 mm

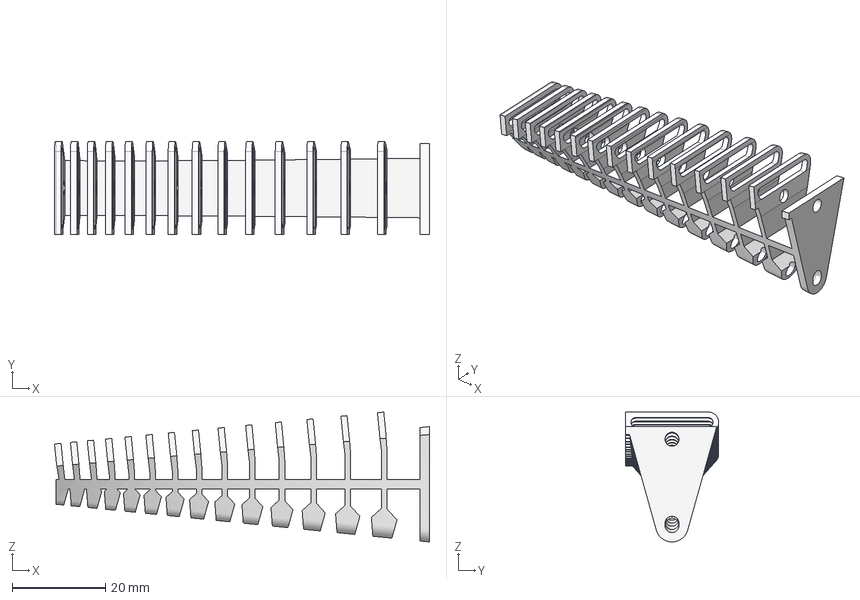
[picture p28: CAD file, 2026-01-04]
3d_files/Finger - without supports.step
80.2 x 20.0 x 27.8 mm

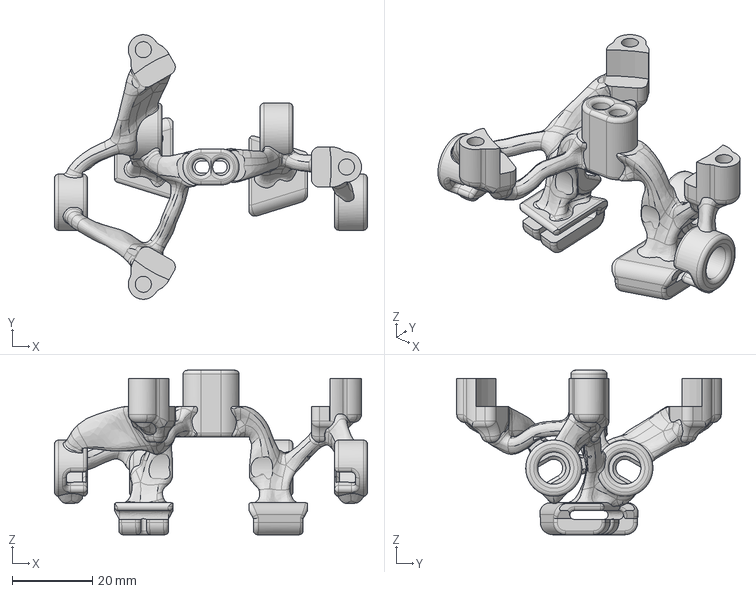
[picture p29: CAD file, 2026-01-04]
3d_files/Finger mount.step
78.0 x 66.0 x 41.0 mm

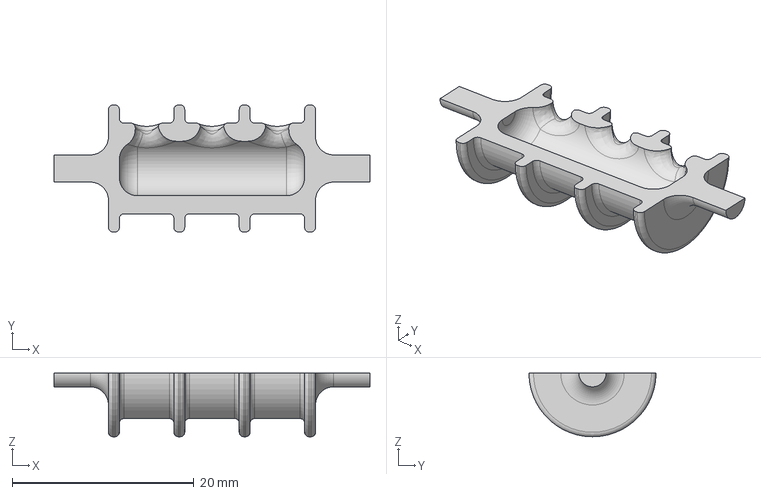
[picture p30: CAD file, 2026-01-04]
3d_files/Finger mount - Small drum half.step
34.8 x 14.0 x 7.00 mm

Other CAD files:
3d_files/Finger - with supports.stl
3d_files/Finger - without supports.stl
3d_files/Finger mold.stl
3d_files/Finger mount - Arm Interface Cap.stl
3d_files/Finger mount - Large drum half.stl
3d_files/Finger mount - Small drum half.stl

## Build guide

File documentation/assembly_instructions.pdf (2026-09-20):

E ASSEMBLY: END-EFFECTOR

E Assembly: End-effector

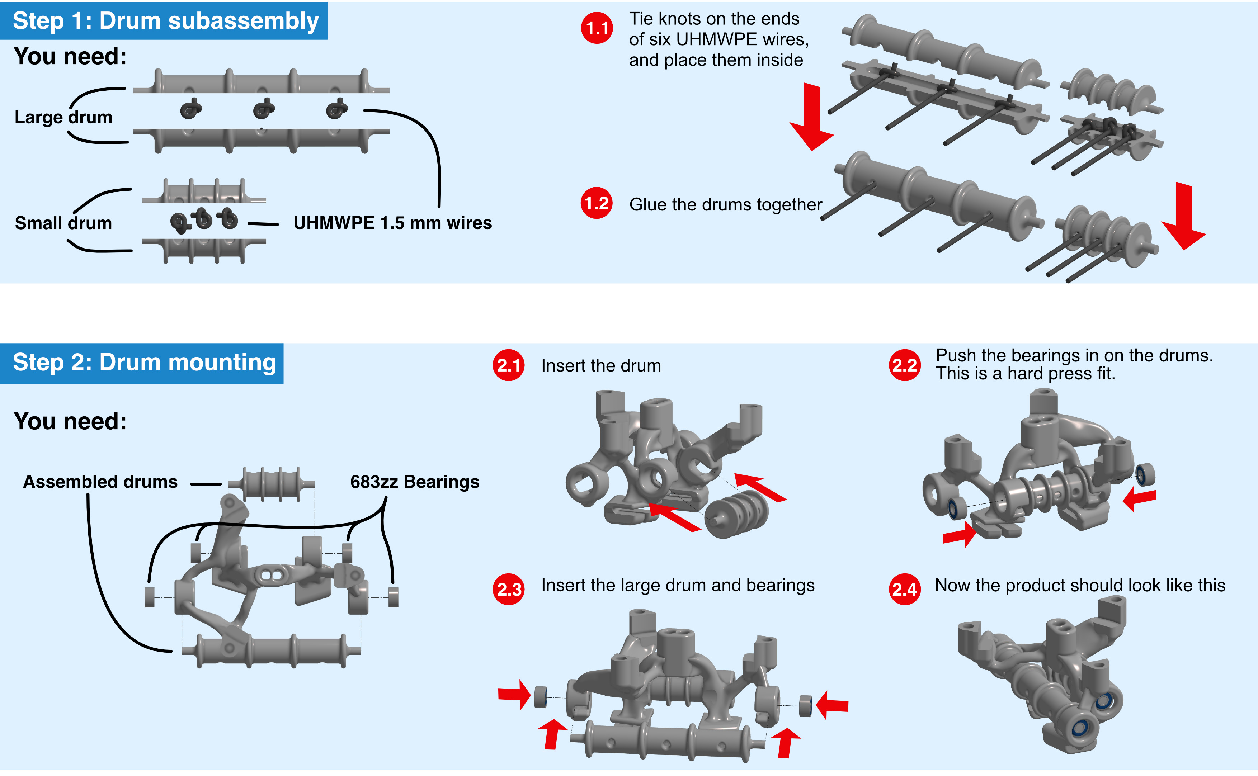
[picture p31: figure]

Page 62 of 70

E ASSEMBLY: END-EFFECTOR

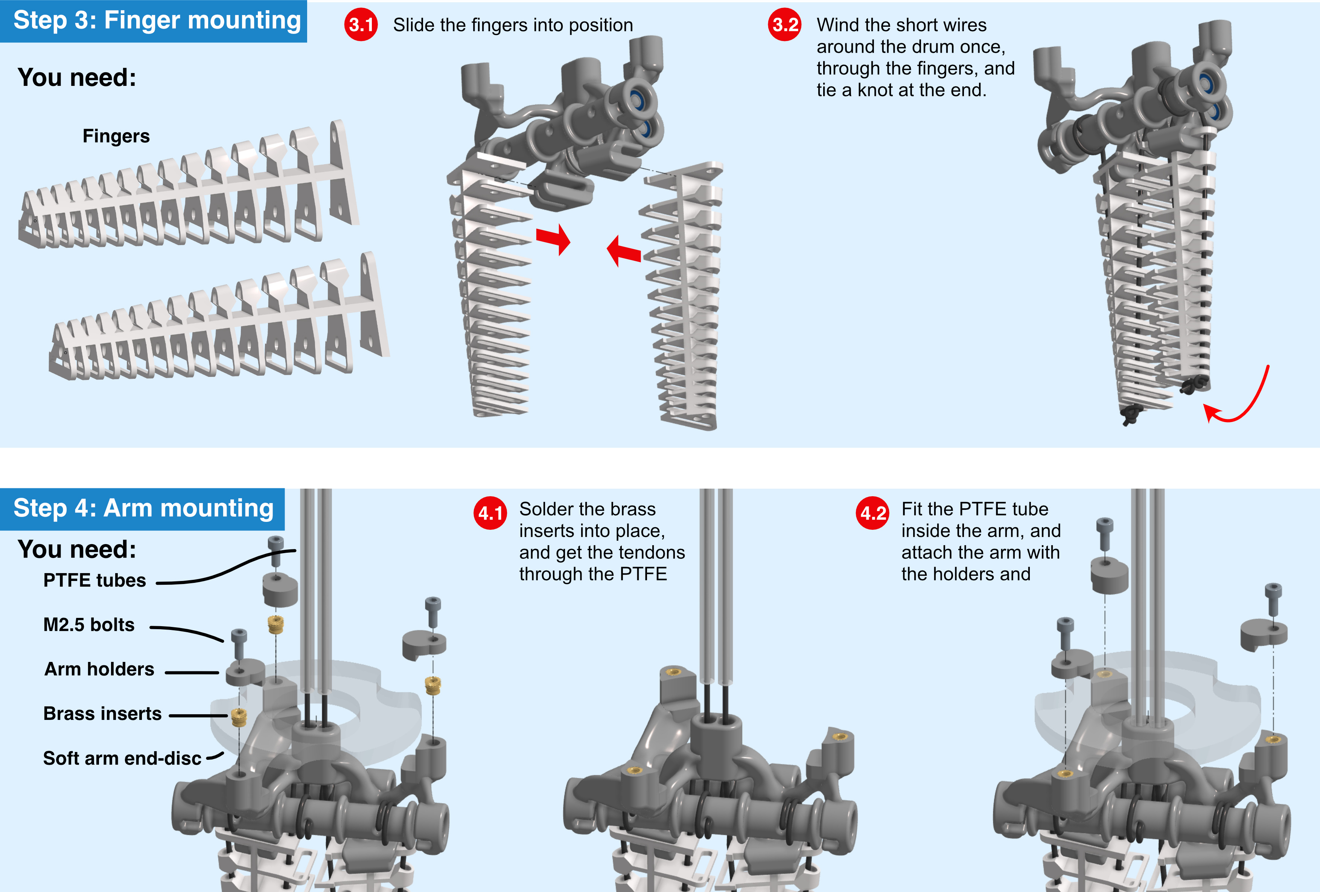
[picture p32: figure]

Page 63 of 70

F ASSEMBLY: ACTUATOR

## F Assembly: Actuator

Page 64 of 70

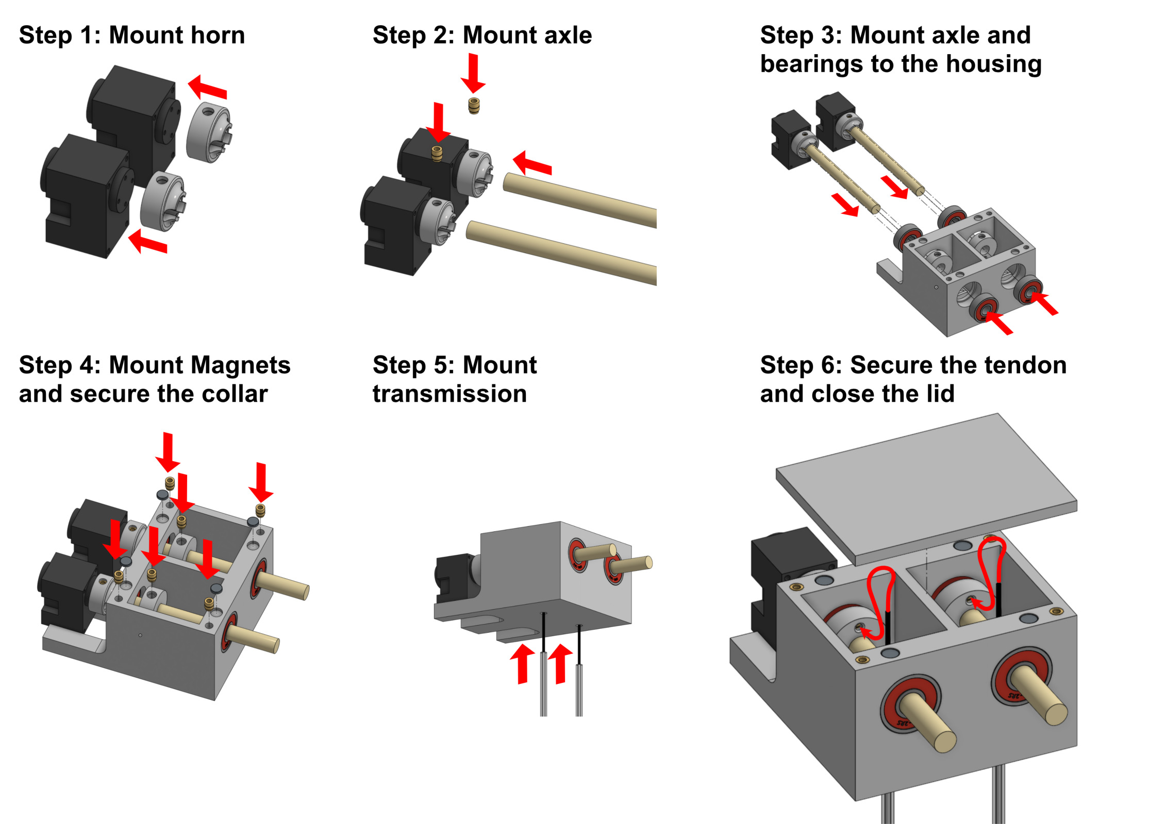
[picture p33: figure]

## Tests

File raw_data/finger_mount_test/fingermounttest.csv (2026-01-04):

Type | Trial number | Force input | Force output
Extensor old | 1 | 10 | 3
Extensor old | 2 | 10 | 3.2
Extensor old | 3 | 10 | 3.4
Extensor old | 4 | 10 | 2.8
Extensor old | 5 | 10 | 3.6
Extensor old | 6 | 10 | 3.8
Extensor old | 7 | 10 | 3.7
Extensor old | 8 | 10 | 3.6
Extensor old | 9 | 10 | 3
Extensor old | 10 | 10 | 4
Extensor old | 11 | 10 | 3.2
Extensor old | 12 | 10 | 3.6
Flexor old | 1 | 10 | 8
Flexor old | 2 | 10 | 6.6
Flexor old | 3 | 10 | 6.2
Flexor old | 4 | 10 | 7.8
Flexor old | 5 | 10 | 7.5
Flexor old | 6 | 10 | 6
Flexor old | 7 | 10 | 7.25
Flexor old | 8 | 10 | 8
Flexor old | 9 | 10 | 7.5
Flexor old | 10 | 10 | 7.5
Flexor old | 11 | 10 | 6.8
Flexor old | 12 | 10 | 7.2
Flexor new | 1 | 10 | 7
Flexor new | 2 | 10 | 7
Flexor new | 3 | 10 | 6.2
Flexor new | 4 | 10 | 5.9
Flexor new | 5 | 10 | 5.8
Flexor new | 6 | 10 | 5.9
Flexor new | 7 | 10 | 6
Flexor new | 8 | 10 | 6.5
Flexor new | 9 | 10 | 6
Flexor new | 10 | 10 | 5.2
Flexor new | 11 | 10 | 5.5
Flexor new | 12 | 10 | 5.6
Extensor new | 1 | 10 | 6.5
Extensor new | 2 | 10 | 6.7
Extensor new | 3 | 10 | 6.2
Extensor new | 4 | 10 | 6.4
Extensor new | 5 | 10 | 6.4
Extensor new | 6 | 10 | 6.6
Extensor new | 7 | 10 | 7.2
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

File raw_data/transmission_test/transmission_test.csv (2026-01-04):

Force input (N) | "Force output (N)"
3 | 1.4
3 | 1.8
3 | 1.6
3 | 1.6
3 | 1.6
3 | 1.4
3 | 1.5
3 | 1.6
3 | 1.6
3 | 1.8
6 | 4
6 | 3.8
6 | 4
6 | 3.8
6 | 4.2
6 | 4.1
6 | 4
6 | 3.7
6 | 3.8
6 | 3.9
9 | 6.2
9 | 6.4
9 | 6.4
9 | 6.1
9 | 6.4
9 | 6.2
9 | 6.4
9 | 6.4
9 | 6.4
9 | 6.2
12 | 8.8
12 | 8.4
12 | 8.4
12 | 8.4
12 | 8.4
12 | 8.4
12 | 8.8
12 | 8.6
12 | 8.8
12 | 8.6
15 | 10.8
15 | 10.4
15 | 10.4
15 | 10.8
15 | 10.6
15 | 10.4
15 | 11.2
15 | 10.4
15 | 10.6
15 | 10.4
18 | 13
18 | 12.8
18 | 13
18 | 12.8
18 | 13.2
18 | 12.8
18 | 12.8
18 | 12.8
18 | 12.8
18 | 12.8

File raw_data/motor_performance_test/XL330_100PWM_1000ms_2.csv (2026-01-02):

Program Time [s] | Current (DXL) | Current external | PWM | Load | State | Round
14.5122 | 0 | 8 | 0 | 0 | 0 | 0
14.5993 | 15 | 10 | 10 | 0 | 0 | 0
14.6853 | 14 | 13 | 10 | -1 | 0 | 0
14.7723 | 14 | 13 | 10 | -2 | 0 | 0
14.8583 | 14 | 13 | 10 | -3 | 0 | 0
14.9452 | 15 | 12 | 10 | -1 | 0 | 0
15.0313 | 15 | 12 | 10 | -1 | 0 | 0
15.1303 | 14 | 10 | 10 | -1 | 0 | 0
15.2292 | 16 | 12 | 10 | -3 | 0 | 0
15.3293 | 15 | 12 | 10 | -4 | 0 | 0
15.4293 | 15 | 12 | 10 | -3 | 0 | 0
15.5293 | 14 | 13 | 10 | -3 | 0 | 0
15.6292 | 15 | 12 | 10 | -2 | 0 | 0
15.7293 | 15 | 12 | 10 | -2 | 0 | 0
15.8283 | 15 | 13 | 10 | -1 | 0 | 0
15.9292 | 14 | 12 | 10 | -2 | 0 | 0
16.0293 | 15 | 13 | 10 | -2 | 0 | 0
16.1282 | 15 | 12 | 10 | -1 | 0 | 0
16.2282 | 15 | 12 | 10 | -2 | 0 | 0
16.3283 | 15 | 12 | 10 | -2 | 0 | 0
16.4282 | 15 | 13 | 10 | -2 | 0 | 0
16.5282 | 14 | 12 | 10 | -3 | 0 | 0
16.6282 | 15 | 12 | 10 | 0 | 0 | 0
16.7272 | 15 | 12 | 10 | -1 | 0 | 0
16.8282 | 15 | 12 | 10 | -1 | 0 | 0
16.9283 | 14 | 13 | 10 | -2 | 0 | 0
17.0272 | 14 | 12 | 10 | -2 | 0 | 0
17.1272 | 15 | 12 | 10 | -1 | 0 | 0
17.2273 | 15 | 12 | 10 | 0 | 0 | 0
17.3272 | 14 | 10 | 10 | -1 | 0 | 1
17.4272 | 15 | 13 | 10 | -4 | 10 | 1
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

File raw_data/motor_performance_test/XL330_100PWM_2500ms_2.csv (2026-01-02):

Program Time [s] | Current (DXL) | Current external | PWM | Load | State | Round
6.94452 | 0 | 6 | 0 | 0 | 10 | 13
7.04552 | 24 | 26 | 140 | 0 | 10 | 13
7.1445 | 27 | 26 | 175 | -2 | 10 | 13
7.24458 | 43 | 45 | 210 | -7 | 10 | 13
7.34554 | 112 | 117 | 245 | -182 | 10 | 13
7.44453 | 167 | 154 | 280 | -917 | 10 | 13
7.54556 | 210 | 208 | 315 | -1862 | 10 | 13
7.64552 | 271 | 266 | 350 | -2426 | 10 | 13
7.74458 | 335 | 325 | 385 | -2765 | 10 | 13
7.84458 | 388 | 367 | 420 | -3013 | 10 | 13
7.94556 | 443 | 429 | 455 | -3102 | 10 | 13
8.04459 | 504 | 490 | 490 | -3079 | 10 | 13
8.14443 | 570 | 561 | 525 | -3065 | 10 | 13
8.24439 | 487 | 480 | 560 | -3055 | 10 | 13
8.3435 | 633 | 636 | 595 | -3097 | 10 | 13
8.44458 | 773 | 754 | 630 | -3530 | 10 | 13
8.54447 | 848 | 821 | 665 | -4201 | 10 | 13
8.6435 | 922 | 894 | 700 | -4677 | 10 | 13
8.74351 | 1000 | 981 | 735 | -4652 | 10 | 13
8.84455 | 1074 | 1050 | 770 | -4627 | 10 | 13
8.94342 | 1041 | 1036 | 805 | -4608 | 10 | 13
9.0434 | 1153 | 1131 | 805 | -4603 | 20 | 13
9.14341 | -4 | 5 | -10 | -4771 | 20 | 13
9.24246 | -10 | 6 | -10 | -4677 | 20 | 13
9.34342 | -12 | 10 | -10 | -3201 | 20 | 13
9.44341 | -14 | 10 | -10 | -1748 | 20 | 13
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

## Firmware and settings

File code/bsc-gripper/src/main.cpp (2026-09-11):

#include <Arduino.h>
#include <config.h>
#include <serial_config.h>
#include <dynamixel_control.h>
#include <load_cell.h>


// Variables used in main.cpp
bool grip = false;
unsigned long last_grip_change = 0;
unsigned long last_print = 0;
int round_i = 0;

static unsigned long lastBtnTime = 0;

// States to hold info
DxlState dxlSt;
LoadCellState lcSt;


// Simple helper for printing
static void print_state(const DxlState &dxlSt, const LoadCellState &lcSt, const GripState &gripSt) {

    for (uint8_t i = 0; i < DXL_ID_CNT; i++) {
        DEBUG_SERIAL.print(dxlSt.current[i]);
        DEBUG_SERIAL.print("\t");
        DEBUG_SERIAL.print(dxlSt.position[i]);
        DEBUG_SERIAL.print("\t");
        DEBUG_SERIAL.print(dxlSt.pwm[i]);
        DEBUG_SERIAL.print("\t");
        DEBUG_SERIAL.print(dxlSt.velocity[i]);
        DEBUG_SERIAL.print("\t");
    }
    for (uint8_t i = 0; i < N_SCALES; i++) {
        DEBUG_SERIAL.print(lcSt.load[i]);
        DEBUG_SERIAL.print("\t");
    }
    DEBUG_SERIAL.print(((int)gripSt)*10);
    DEBUG_SERIAL.print("\t");

    
    DEBUG_SERIAL.print(round_i);
    DEBUG_SERIAL.print("\t");
    
    DEBUG_SERIAL.println();
}


void setup() {

  // Set up pins
  pinMode(SCOPE_PIN_A, OUTPUT);
  pinMode(SCOPE_PIN_B, OUTPUT);
  pinMode(BTN_PIN, INPUT_PULLUP);
  digitalWrite(SCOPE_PIN_A, LOW);
  digitalWrite(SCOPE_PIN_B, LOW);

  // Use UART port of DYNAMIXEL Shield to debug.
  DEBUG_SERIAL.begin(115200);
  DEBUG_SERIAL.print("Test test");

  // Initialize motors
  dxl_init();

  // Only initialize if we need to test - flag set in config.h
  if (debugLoadCells) load_cell_init();
  
// Not needed anymore
  // dxl_auto_calibration(250);
  

}

void loop() {
  

  unsigned long now = millis();

  // Toggle grip command with external button
  if (digitalRead(BTN_PIN) == LOW && (now - lastBtnTime > BTN_DEBOUNCE)) {
    lastBtnTime = now;
    // button action
    grip = !grip; // Change gripping command
    if (grip) round_i++;
  }

  // Toggle grip command periodically with a MS period - not used anymore
  if (now - last_grip_change >= GRIPPING_PERIOD_MS) {
    
    last_grip_change = now;                 // reset timer
    // ---- do your timed action here ----
    grip = !grip; // Change gripping command every GRIPPING_PERIOD_MS
    if (grip) round_i++;


  }

  if (now - last_print >= SAMPLING_PERIOD_MS) {
      last_print = now;                 // reset timer

      digitalWrite(SCOPE_PIN_B, HIGH); // Used for debuging

      if(debugLoadCells) {
              lcSt = load_cell_read();
        }
      digitalWrite(SCOPE_PIN_B, LOW); // Used for debuging

      digitalWrite(SCOPE_PIN_A, HIGH); // Used for debuging

      dxlSt = dxl_read_state();

      digitalWrite(SCOPE_PIN_A, LOW); // Used for debuging

      // Checks if we got a timeout error, and if yes we reinit motors.
      if (dxl_motors_timeout()) {
            // DEBUG_SERIAL.println("Motors timed out");
            dxl_init();            
            // dxl_auto_calibration(250);
            grip = false;

      }

      dxl_filter_current(dxlSt);

      
      digitalWrite(SCOPE_PIN_B, HIGH); // Used for debuging

      
      GripState gripSt = dxl_get_grip_state();

      print_state(dxlSt, lcSt, gripSt);
      digitalWrite(SCOPE_PIN_B, LOW);


      dxl_update_state(dxlSt, grip);

      

    }
  
    





}

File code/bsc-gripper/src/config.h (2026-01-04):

// hvordan kan det vlre at det fucker altid hele tiden? - Asbjærb Schroll Graae

#pragma once
#include <Arduino.h>// -------------------- General config --------------------


#define MAX_CURRENT          300
#define MAX_PWM 600
#define GRIPPING_PERIOD_MS   1000000
#define SAMPLING_PERIOD_MS   100 // If using load cell this needs to be 100ms.

#define DXL_VELOCITY_DEADBAND 5
#define CONTROL_CLOSING_SLOPE_FLEXOR 20

// Control
#define OPEN_FLEX_SLOPE 0
#define OPEN_EXTE_SLOPE 0
#define OPEN_FLEX_LIMIT -5
#define OPEN_EXTE_LIMIT 150

#define CLOSING_TIME 1000 // ms
#define CLOSING_FLEX_SLOPE 30
#define CLOSING_EXTE_SLOPE 0
#define CLOSING_FLEX_LIMIT 500
#define CLOSING_EXTE_LIMIT -200

#define TIGHTEN_TIME 500 // ms
#define TIGHTEN_FLEX_SLOPE 10
#define TIGHTEN_EXTE_SLOPE 10
#define TIGHTEN_FLEX_LIMIT 600
#define TIGHTEN_EXTE_LIMIT -20

#define HOLDING_TIME 0 // ms
#define HOLDING_FLEX_SLOPE 0
#define HOLDING_EXTE_SLOPE 0
#define HOLDING_FLEX_LIMIT 250
#define HOLDING_EXTE_LIMIT -5

#define RELEASING_TIME 0 // ms
#define RELEASING_FLEX_SLOPE 0
#define RELEASING_EXTE_SLOPE 0
#define RELEASING_FLEX_LIMIT -200
#define RELEASING_EXTE_LIMIT 600

#define CURRENT_DEADBAND 50
#define MAX_ACTUATION_CONTROL 600

#define BTN_DEBOUNCE 300 // ms

#define RUNNING_AVG 1


// -------------------- Load cell pins --------------------
#define ABC_LOAD_CELL_CLK   5
#define C_LOAD_CELL_DT     6

#define N_SCALES 1

#define C_LOAD_CELL_SCALE 223.12


// -------------------- Scope pins ------------------------
#define SCOPE_PIN_A 9
#define SCOPE_PIN_B 10

#define BTN_PIN 4

// -------------------- Dynamixel config ------------------


#define DXL_SHIELD_UART_RX 7
#define DXL_SHIELD_UART_TX 8
#define DXL_DIR_PIN 2


const float DXL_PROTOCOL_VERSION = 2.0f;


const bool debugLoadCells = false;   // or false


const uint8_t DXL_ID_EXTENSOR = 8;
const uint8_t DXL_ID_FLEXOR   = 9;

const uint8_t IDX_EXTENSOR = 0;
const uint8_t IDX_FLEXOR   = 1;

const uint8_t BROADCAST_ID = 254;
const uint8_t DXL_ID_CNT   = 2;
const uint8_t DXL_ID_LIST[DXL_ID_CNT] = {DXL_ID_EXTENSOR, DXL_ID_FLEXOR};

// SyncWrite (Goal Position)
const uint16_t SW_START_ADDR = 100; // 100 = Goal PWM, 102 = Goal Current, 116 = Goal Positiion
const uint16_t SW_ADDR_LEN   = 2; // PWM and Current -> 2, Position -> 4
const uint16_t USER_PKT_BUF_CAP = 128;

// XL330 feedback block
constexpr uint16_t XL330_ADDR_PRESENT_PWM      = 124;
constexpr uint16_t XL330_BLOCK_LEN          = 12;  // PWM+Current+Vel+Pos

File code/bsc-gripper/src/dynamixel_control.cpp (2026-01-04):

#include <dynamixel_control.h>
#include <config.h>
#include <serial_config.h>

// This namespace is required to use Control table item names
using namespace ControlTableItem;


Dynamixel2Arduino dxl(DXL_SERIAL, DXL_DIR_PIN);

static uint8_t user_pkt_buf[USER_PKT_BUF_CAP];

typedef struct sw_data {
  int32_t goal_value;
} __attribute__((packed)) sw_data_t;

static sw_data_t sw_data[DXL_ID_CNT];
static DYNAMIXEL::InfoSyncWriteInst_t sw_infos;
static DYNAMIXEL::XELInfoSyncWrite_t info_xels_sw[DXL_ID_CNT];

static GripState s_grip_state = GRIP_RELEASING;

static int32_t s_control[DXL_ID_CNT] = {0,0};


static int32_t current_avg[RUNNING_AVG][DXL_ID_CNT];
static int8_t s_avg_index = 0;


void dxl_init() {

    dxl.begin(1000000);
    dxl.setPortProtocolVersion(DXL_PROTOCOL_VERSION);

    // Wait for motor power
    while (!dxl.ping(DXL_ID_FLEXOR) || !dxl.ping(DXL_ID_EXTENSOR)) {
        // DEBUG_SERIAL.println("Motors not reacting to ping...");
        delay(1000);
    }
    // DEBUG_SERIAL.println("Ping succesfull!");

    // Initial setup
    for (uint8_t i = 0; i < DXL_ID_CNT; i++) {
        dxl.torqueOff(DXL_ID_LIST[i]);
        dxl.setOperatingMode(DXL_ID_LIST[i], OP_PWM);
        dxl.writeControlTableItem(CURRENT_LIMIT, DXL_ID_LIST[i], MAX_CURRENT);
        dxl.writeControlTableItem(PWM_LIMIT, DXL_ID_LIST[i], MAX_PWM);
        dxl.writeControlTableItem(HOMING_OFFSET, DXL_ID_LIST[i], 0);
        dxl.writeControlTableItem(TEMPERATURE_LIMIT, DXL_ID_LIST[i], 60);
    }

    s_grip_state = GRIP_RELEASING;

    dxl.torqueOn(BROADCAST_ID);

    // Setup SyncWrite
    sw_infos.packet.p_buf = user_pkt_buf;
    sw_infos.packet.buf_capacity = USER_PKT_BUF_CAP;
    sw_infos.packet.is_completed = false;
    sw_infos.addr = SW_START_ADDR;
    sw_infos.addr_length = SW_ADDR_LEN;
    sw_infos.p_xels = info_xels_sw;
    sw_infos.xel_count = 0;

    for (uint8_t i = 0; i < DXL_ID_CNT; i++) {
        info_xels_sw[i].id = DXL_ID_LIST[i];
        info_xels_sw[i].p_data = (uint8_t*)&sw_data[i].goal_value;
        sw_infos.xel_count++;
    }
    sw_infos.is_info_changed = true;
}


void dxl_set_goal_values(int32_t goalFlexor, int32_t goalExtensor) {
    sw_data[IDX_FLEXOR].goal_value   = goalFlexor;
    sw_data[IDX_EXTENSOR].goal_value = goalExtensor;
    sw_infos.is_info_changed = true;
    dxl.syncWrite(&sw_infos);
}


bool dxl_read_feedback_block(uint8_t id, uint8_t idx, DxlState &out) {
    uint8_t buf[XL330_BLOCK_LEN];

    int recv_len = dxl.read(id,
                            XL330_ADDR_PRESENT_PWM,
                            XL330_BLOCK_LEN,
                            buf,
                            XL330_BLOCK_LEN
                            );

    if (recv_len != XL330_BLOCK_LEN) {
        // read failed or timed out
        return false;
    }

    auto get16 = [&](uint8_t offset) -> int16_t {
        return (int16_t)( (uint16_t)buf[offset] |
                          ((uint16_t)buf[offset + 1] << 8) );
    };

    auto get32 = [&](uint8_t offset) -> int32_t {
        return (int32_t)( (uint32_t)buf[offset] |
                          ((uint32_t)buf[offset + 1] << 8) |
                          ((uint32_t)buf[offset + 2] << 16) |
                          ((uint32_t)buf[offset + 3] << 24) );
    };

    // Layout in the 12-byte block:
    // 0–1: PWM (124–125)
    // 2–3: Current (126–127)
    // 4–7: Velocity (128–131)
    // 8–11: Position (132–135)

    out.pwm[idx]      = get16(0);
    out.current[idx]  = get16(2);
    out.velocity[idx] = get32(4);
    out.position[idx] = get32(8);

    return true;
}

DxlState dxl_read_state() {
    DxlState st;
    // flexor (index 0)
    dxl_read_feedback_block(DXL_ID_FLEXOR, IDX_FLEXOR, st);

    // extensor (index 1)
    dxl_read_feedback_block(DXL_ID_EXTENSOR, IDX_EXTENSOR, st);


    return st;                                          
}

void dxl_filter_current(DxlState& st) {
    for (uint8_t i = 0; i < DXL_ID_CNT; i++) {
        current_avg[s_avg_index][i] = st.current[i];
    }

    s_avg_index = (s_avg_index + 1) % RUNNING_AVG;

    for (uint8_t i = 0; i < DXL_ID_CNT; i++) {
        int32_t sum = 0;
        for (uint8_t j = 0; j < RUNNING_AVG; j++) {
            sum += current_avg[j][i];
        }
        st.current[i] = sum / 5;
    }
}


bool dxl_motors_timeout() {
    auto err = dxl.getLastLibErrCode();
    return (err == DXL_LIB_ERROR_TIMEOUT);
}


void dxl_update_state(const DxlState& st, bool grip) {
    switch (s_grip_state)
    {
    case GRIP_OPEN:
        /* code */
        


        if (grip) {
            s_grip_state = GRIP_CLOSING;
        }

        s_control[IDX_FLEXOR] = OPEN_FLEX_LIMIT;
        s_control[IDX_EXTENSOR] = OPEN_EXTE_LIMIT; 


        break;
    
    case GRIP_CLOSING:
        /* code */

        if (st.pwm[IDX_FLEXOR] >= CLOSING_FLEX_LIMIT*0.99 and st.pwm[IDX_EXTENSOR] <= CLOSING_EXTE_LIMIT*0.99) {
            s_grip_state = GRIP_TIGHTEN;
            break;
        }


        s_control[IDX_FLEXOR] += CLOSING_FLEX_SLOPE;
        s_control[IDX_EXTENSOR] = CLOSING_EXTE_LIMIT; 
        
        /*
        if (abs(st.velocity[IDX_FLEXOR]) < DXL_VELOCITY_DEADBAND and abs(st.current[IDX_FLEXOR]) > CURRENT_DEADBAND) {
            s_grip_state = GRIP_HOLDING;
        }
        */

        break;

    case GRIP_TIGHTEN: // 
        /* code */

        if (st.pwm[IDX_FLEXOR] >= TIGHTEN_FLEX_LIMIT*0.99 and st.pwm[IDX_EXTENSOR] >= TIGHTEN_EXTE_LIMIT*0.99) {
            s_grip_state = GRIP_HOLDING;
            break;
        }


        s_control[IDX_FLEXOR] += TIGHTEN_FLEX_SLOPE;
        s_control[IDX_EXTENSOR] += TIGHTEN_EXTE_SLOPE; 


        /*
        if (abs(st.velocity[IDX_FLEXOR]) < 5) {
            s_grip_state = GRIP_HOLDING;
        }
        */

        break;
    
    case GRIP_HOLDING:
        /* code */
        s_control[IDX_FLEXOR] = HOLDING_FLEX_LIMIT;
        s_control[IDX_EXTENSOR] = HOLDING_EXTE_LIMIT;

        
        if (!grip) {
            s_grip_state = GRIP_RELEASING;
        }

        break;
    

    case GRIP_RELEASING:
        /* code */

        
        if (abs(st.velocity[IDX_EXTENSOR]) < DXL_VELOCITY_DEADBAND and abs(st.pwm[IDX_EXTENSOR]) > MAX_ACTUATION_CONTROL*0.75) {
            s_grip_state = GRIP_OPEN;
        } 

        s_control[IDX_FLEXOR] = RELEASING_FLEX_LIMIT;
        s_control[IDX_EXTENSOR] = RELEASING_EXTE_LIMIT;



        break;
    
    default:
        s_grip_state = GRIP_RELEASING;
        break;
    }

    // Send values to the motors
    dxl_set_goal_values(s_control[IDX_FLEXOR], s_control[IDX_EXTENSOR]);

}

GripState dxl_get_grip_state() {
    return s_grip_state;
     

}

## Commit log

2026-09-20 Adjust image size for system overview diagram
    Updated image size for the Gripper System Overview in README.
2026-09-20 Adjust image size in README for clarity
    Updated image size for the Gripper System Overview.
